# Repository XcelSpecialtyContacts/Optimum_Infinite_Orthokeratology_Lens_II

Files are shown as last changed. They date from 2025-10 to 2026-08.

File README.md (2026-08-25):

# Optimum Infinite Orthokeratology Lens II

## Overview

This project supports the production workflow for the **Optimum Infinite Orthokeratology Lens II** design at X-Cel Specialty Contacts.

The overall system is intended to:

1. Accept customer / ECP order inputs directly in **JD Edwards Configurator**
2. Generate the required production data in JDE, including the **Lab File** and **Invoice**
3. Generate DAC International ALM **point files** from JDE production data
4. Automatically invoke point-file generation during ALM job processing
5. Use a custom ALM manufacturing program (**LSID**) to cut lens surfaces from the generated point files
6. Support lathe-file generation through updates to **RGPLogin.exe**

This repository is primarily the source and documentation hub for the **`oiol2` point-file generator** and its integration into the broader manufacturing workflow.

---

## System Components

The complete production solution includes four major components:

1. **JD Edwards Configurator**
2. **`oiol2` Point File Generator**
3. **DAC ALM LSID (`lsXPF`)**
4. **RGPLogin.exe modifications**

Not all of these components are fully version-controlled in this repository. This repository focuses mainly on:

- the Python source code for `oiol2`
- launcher scripts used to invoke `oiol2`
- supporting configuration and data files
- tests
- documentation describing system integration

---

## Current Implementation Summary

### 1. JD Edwards Configurator

- A new item was created for this project: **Item 733**
- For Item 733, Customer Service enters the ECP's inputs directly into JDE Configurator
- No intermediate calculator / translator is required before entering order data into Configurator
- JDE produces a **Lab File** containing the data needed to generate lathe point files
- The invoice has been mocked up in the JDE **Test** environment
- Full testing of the invoice is still required before promotion to the **Live** environment

### 2. `oiol2` Point File Generator

`oiol2` is the Python program that reads production data and generates DAC ALM point files.

#### Original concept

The original plan was to host `oiol2` on a server and have the ALM call it remotely. In that design:

- the ALM would pass arguments identifying the lens/job to cut
- the server would generate the point files
- the server would return an exit code to the ALM
- the ALM would retrieve the generated point files and continue processing

This approach was not implemented due to credential, access, and IT support complexities between systems.

#### Implemented approach

The implemented solution runs `oiol2` **locally on the ALM PC**.

This avoids cross-system credential and server access issues. In the implemented design:

- the ALM PC runs a local 32-bit Python runtime
- `oiol2` is installed locally on the ALM PC
- the ALM invokes `oiol2` through a batch launcher
- `oiol2` generates the required point files locally
- the exit code is returned back to the ALM workflow

#### 32-bit runtime port

The development version of `oiol2` was originally built using:

- Python 3.11
- 64-bit Windows
- a Conda-based development environment

Because the ALM-connected PCs run **Windows 10 LTS 32-bit**, `oiol2` was ported to run under a standalone **Python 3.11 32-bit** installation.

Notes:

- `matplotlib` was removed from the ALM runtime path because plotting was only needed for development
- `numpy` required installation of the **Microsoft Visual C++ Redistributable**
- the 32-bit version was validated on the ALM-connected PC

#### Front-surface laser engraving

`oiol2` now includes the WO number as laser-writing data in the front-surface DAC point file.

The generated front point file uses the **`FRL`** format (front side, radial format, laser writing). The laser-writing block is written after the diagnostic-mark count and before the first surface definition.

For the current production configuration:

- the laser text is the WO number passed with `--wo`
- the engraving radius is calculated as `lens diameter / 2 - edge_offset_mm`
- the default engraving direction is **270.0 degrees**
- the default character height is **0.400 mm**
- the default character spacing factor is **1.0**
- the default edge offset is **0.400 mm**

The fixed laser-writing parameters are maintained in the `[laser_writing]` section of `lens_design.toml`, while the WO number and lens diameter are determined for each production job.

This implementation was tested successfully in the production ALM workflow.

### 3. DAC ALM LSID (`lsXPF`)

A new LSID named **`lsXPF`** was developed with John Vanover.

`lsXPF` is responsible for:

- processing the point files generated for the lens surface
- calling the `oiol2` launcher so point files can be generated when needed
- continuing the ALM cutting process after point files are available

### 4. RGPLogin.exe

The source for `RGPLogin.exe` is written in Microsoft VB.

This program was modified so that when a job is set up in production, it creates the appropriate **Lathe File** needed by the ALM workflow for this project.  Version 1.17 is required for this process.

---

## Process Flow

```mermaid
flowchart TD
    A[JDE Produces Lab File] --> B[RGPLogin Creates Lathe File]
    B --> C[ALM Reads Lathe File]
    C --> D[ALM Executes lsXPF]
    D --> E[lsXPF calls launcher script]
    E --> F[Launcher script executes oiol2.main]
    A --> G[oiol2 reads Lab File data]
    F --> G
    G --> H[oiol2 generates point files]
    H --> I[oiol2 returns exit code to launcher]
    I --> J[Launcher places point files in ALM-accessible location]
    J --> K[Launcher returns exit code to lsXPF]
    K --> L[lsXPF cuts surface using point file]
```

### Execution chain

**S1**
`D:\oiol2\call_oiol2_point_file_gen.bat --wo ###`

**E1**
`D:\Python32\python.exe -m oiol2.main --wo ###`

**S2**
`oiol2.main`

**L1**
`D:\oiol2\test_dacfiles\`

---

## Repository Purpose

This repository should contain the **source of truth** for the `oiol2` software and its deployment documentation.

It is intended to include:

* Python source code
* configuration templates
* supporting data files
* test code
* launcher scripts
* system documentation
* integration notes for JD Edwards, `lsXPF`, and `RGPLogin.exe`

It should **not** be used to store:

* machine-specific installed copies
* build artifacts
* virtual environments
* log files
* Python cache folders
* generated point files used only for testing or local runs

---

## Repository Layout

Planned / preferred layout:

```text
Optimum_Infinite_Orthokeratology_Lens_II/
│
├── README.md
├── .gitignore
├── pyproject.toml
├── pytest.ini
├── environment.yml
├── requirements.txt
├── requirements_win32.txt
├── requirements_32bit_runtime.txt
│
├── configs/
├── data/
├── docs/
├── scripts/
├── src/
│   └── oiol2/
├── tests/
├── examples/
└── archive/
```

### Key directories

* **`src/oiol2/`**
  Main Python package for point-file generation
* **`configs/`**
  Configuration templates and sample TOML files
* **`data/`**
  Lens design data and lookup/reference files
* **`scripts/`**
  Launcher and helper scripts used for ALM execution and testing
* **`tests/`**
  Automated tests for parser and geometry logic
* **`docs/`**
  Project documentation, architecture notes, deployment notes, and design references
* **`examples/`**
  Sample lab files, sample outputs, and example inputs/outputs as needed
* **`archive/`**
  Legacy or reference material retained for historical reasons but not part of the active runtime path

---

## Development vs Deployment

### Development environment

Development was originally performed using:

* Python 3.11
* 64-bit Windows
* Conda environment
* optional plotting for geometry/debug work

### Deployment environment

The ALM runtime environment uses:

* Windows 10 LTS 32-bit
* standalone Python 3.11 32-bit
* locally installed `oiol2`
* launcher batch script
* Microsoft Visual C++ Redistributable for `numpy`
* Reconfigured `XASPFRNT.TPL` file in the ALM folder on the DAC PC (see `docs/ALM_with_laser_set-up.md`)

---

## ALM Deployment Layout

Example deployment layout on the ALM PC:

```text
D:\
├── Python32\
└── OIOL2\
    ├── call_oiol2_point_file_gen.bat
    ├── configs\
    ├── data\
    ├── logs\
    ├── src\
    └── test_dacfiles\
```

This installed layout is documented for deployment purposes, but the installed copy itself should not be committed as a duplicate code tree in Git.

---

## Status

### Completed

- [X] Item 733 created in JD Edwards Configurator
- [X] Direct ECP input workflow established in Configurator
- [X] Lab File generation working in JDE
- [X] `oiol2` developed and working in development environment
- [X] `oiol2` ported to Python 3.11 32-bit runtime
- [X] local ALM execution model implemented
- [X] `lsXPF` LSID created to process point files and invoke `oiol2`
- [X] `RGPLogin.exe` modified to generate the required Lathe File
- [X] WO laser engraving integrated into the front-surface `FRL` point file
- [X] laser-writing implementation validated in production
- [X] complete invoice testing in JDE Test environment
- [X] move invoice changes to JDE Live environment after validation
- [X] Install `lsXPF` and `oiol2` on ALM03, ALM06, ALM07, and ALM08

### Open items

- [ ] create an `lsXPF` version for ALM01 and ALM02

---

## Runtime Notes

* Some Python modules (e.g., `numpy`, `sympy`) on the 32-bit ALM system require the **Microsoft Visual C++ Redistributable**
* plotting support was intentionally removed from the ALM runtime path
* machine-specific config files should not be committed to version control unless sanitized for reuse

---

## Notes

This repository documents a manufacturing integration effort that spans ERP configuration, production setup, ALM machine integration, and Python-based point-file generation. The Python code in this repository is only one part of the overall solution, but it is the primary software component maintained here.

---

## Maintainer

### [X-Cel Specialty Contacts](https://www.xcelspecialtycontacts.com/)

[Allen Gilliard](agilliar@xcelspecialtycontacts.com)

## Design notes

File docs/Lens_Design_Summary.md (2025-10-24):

## Constraints for Optimum Infinite Orthokeratology Lenses II
Patient Spherical Error:  -0.25 to -6.00 diopters
Patient Cylinder Error:  0.00 to -1.75 diopters
Lens Diameter:  9.5 to 12.0 mm
Center Thickness:
Central Base Curve Radius:  6.50 to 10.50 mm
Optical Zone Semi Chord: 2.50 to 3.50 mm
Return Zone Width: 0.75 to 1.5 mm
Return Zone Depth: 0 to 1.0 mm
Return Zone Radius: No constraint
Landing Zone Angle: 25$^\circ$ to 50$^\circ$
Landing Zone Width: 0.5 to 2.75 mm
Peripheral Edge Curve Width: minimum 0.04 mm
Dioptric Powers: -2.00 to +2.00 diopters
Lens Material: Optimum Infinite (tisilfocon A)

## X-Cel Specialty Contacts Othokeratology Lens Specifics
| Paramater | Maximum | Minimum | Increments |
|---|---|---|---|
| Lens Diamter (mm) | 12.0 | 9.5 | 0.1 |
| Central Zone Radius (diopter) | 51.875 | 32.125 | 0.125 |
| Central Zone Diameter (mm) | 7.0 | 5.0 | 0.1 |
| Return Zone Depth (mm) | 1.00 | 0.00 | 0.01 |
| Return Zone Width (mm) | 1.0 | 1.0 | 0 |
| Landing Zone Angle ($^\circ$) | 50 | 25 | 1 |
| Landing Zone Width (mm) | 2.75 | 0.50 | \* See Note |
| Peripheral Edge Curve Depth (mm) | 0.23 | 0.16 | 0.01 |
| Peripheral Edge Curve Width (mm) | 0.4 | 0.4 | 0 |
| Center Thickness Minimum (mm) | 0.09 | 0.50 | 0.01 |
| Central Zone Boundary Junction Thickness Minimum (mm) | 0.08 | 1.0 | \* See Note |
| Lens Power (diopter) | +2.00 | -2.00 | 0.25 |
| Edge Thickness (mm) | 0.11 | 0.11 | 0 |

### Notes:
1. ECP can specify Lens Diameter but the default is 10.5 mm.  The ECP can make adjustments to the diameter in 0.1 mm steps.
2. ECP can specify Central Zone Diameter but the default is 6.0 mm.  The ECP can make adjustments to the Central Zone diameter in 0.1 mm steps.
3. Central Zone Radius is initally selected by patient's flat K value and the patient's spherical error.  The ECP can make adjustments to the radius in 0.125 diopter steps.
4. Return Zone Depth is initally selected by patient's flat K value and the patient's spherical error.  The ECP can make adjustments to the depth in 0.01 mm steps.
5. Return Zone Width is set to 1.0 mm.
6. Landing Zone Angle is initally selected by patient's flat K value and the patient's spherical error.  The ECP can make adjustments to the angle in 1 degree steps.
7. Landing Zone Width is calculated.
8. ECP can specify Peripheral Edge Curve Depth but the default is 0.21 which generally equates to aproximately a 11.5 mm peripheral curve radius.  The ECP can make adjustments to the depth in 0.01 mm steps.
9. Peripheral Edge Curve Width is set to 0.4 mm.
10. ECP can specify Center Thickness but the default is 0.24 mm.  The ECP can make adjustments to the diameter in 0.01 mm steps.
11. Central Zone Boundary Junction Thickness Minimum is set to 0.18.
12. ECP can specify Lens Powerer but the default is +0.75 diopters.  The ECP can make adjustments to the diameter in 0.25 diopter steps.
13. Edge Thickness is set to 0.11 mm.

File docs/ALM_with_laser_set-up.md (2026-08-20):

To eliminate the ALM from looking for a BC to FC clocking alignment mark on axial symetric parts with laser engraving a file in the ALM control software will need to be edited.

Edit the file named XASPFRNT.TPL

Search for the function named `set_c_zero`.
Once found, a few lines into the function you will see `ERROR = 0`.
Insert a line after this line.

`if {torics+bisym+dmn}+otpts = 0 m99'

Save the file.

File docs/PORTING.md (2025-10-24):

| Legacy name | New name | Notes (units/sign) | Tests added | Date |
|---|---|---|---|---|
| SagSphere | sag_sphere | y in mm; raises if y>R | test_geometry_basic| 2025-10-21 |
| PowerFromRadius | radius_to_surface_power | air->lens, mm->D | test_geometry_basic| 2025-10-21 |

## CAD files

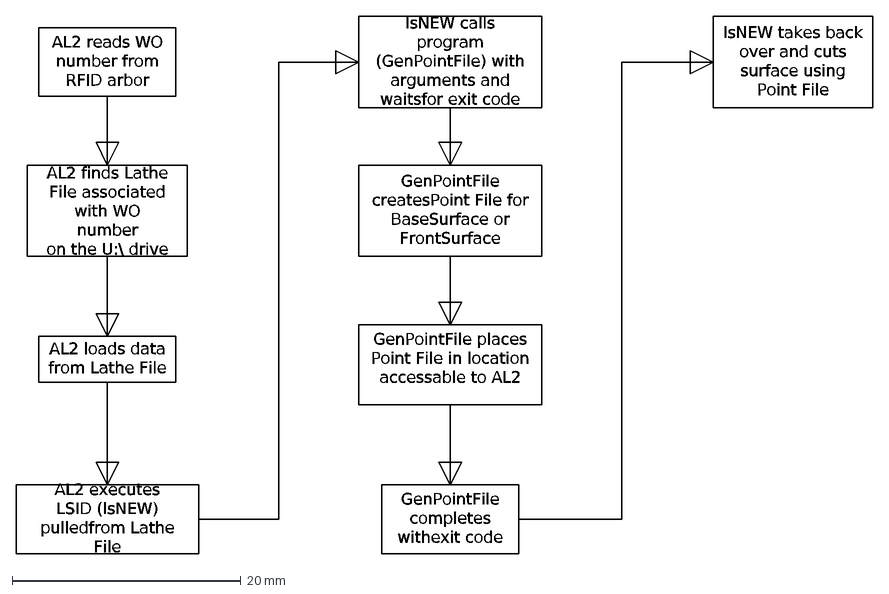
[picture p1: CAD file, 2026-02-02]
docs/ALM_Lathe_Process_2601290831.dxf
lsNEW calls program (GenPointFile) with arguments and waits for exit code
GenPointFile creates Point File for Base Surface or Front Surface
GenPointFile places Point File in location accessable to AL2
AL2 reads WO number from RFID arbor
AL2 finds Lathe File associated with WO number on the U:\ drive
AL2 loads data from Lathe File
AL2 executes LSID (lsNEW) pulled from Lathe File
GenPointFile completes with exit code
lsNEW takes back over and cuts surface using Point File

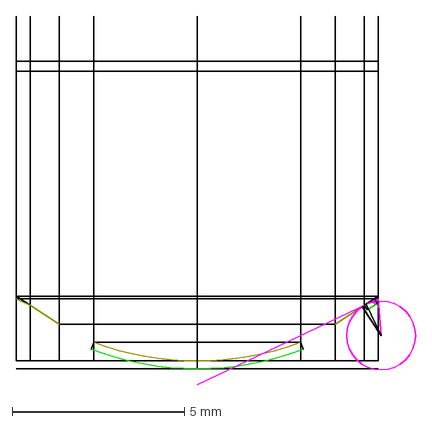
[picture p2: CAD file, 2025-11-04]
docs/design_mock_up_2510240940.dxf
11.6 x 10.7 mm

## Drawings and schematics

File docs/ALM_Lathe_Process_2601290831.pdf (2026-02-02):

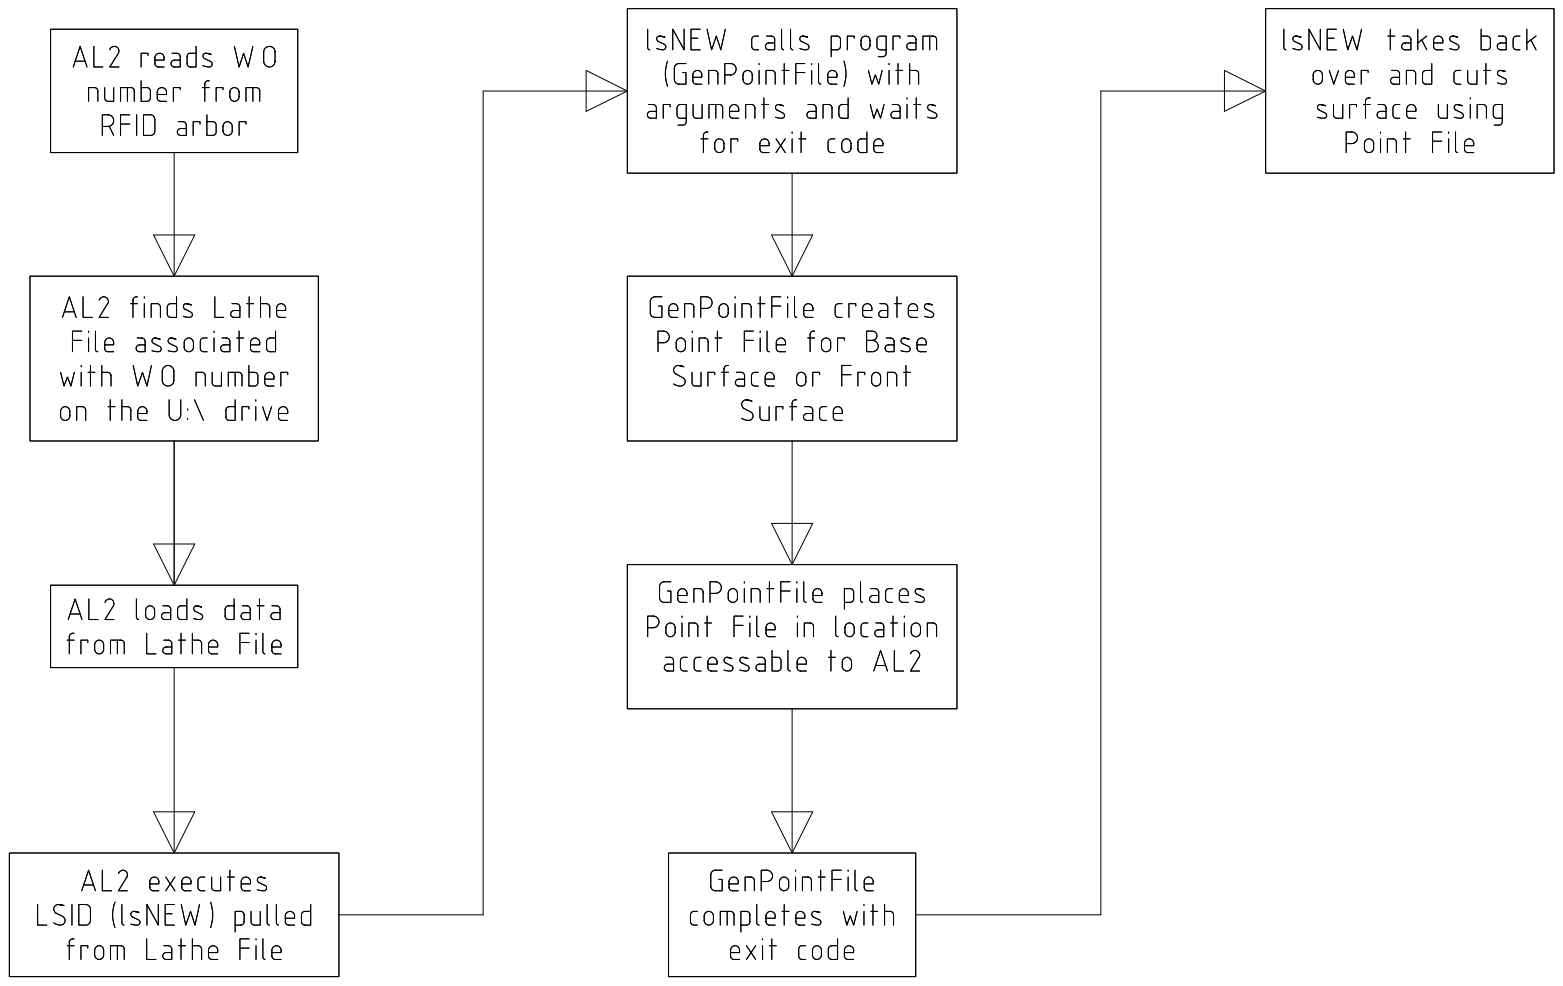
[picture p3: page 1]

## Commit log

2025-10-21 feat: scaffold OIOL2 with modular src package, config, scripts, tests, env
    [CRT_SKUs.csv]
2025-10-24 Working on the optic zone meridional points
    [design_mock_up_2510240940.dxf]
2025-10-31 Drafted code for calculating Base Surface
    [design_mock_up_2510240940.dxf]
2025-11-03 Drafted code for calculating Base Surface and Front Surface
    [design_mock_up_2510240940.dxf]
2025-11-04 Finished generating points.
    [#design_mock_up_2510240940.dxf, design_mock_up_2510240940.dxf]
2026-02-02 Last update
    [ALM_Lathe_Process_2601290831.dxf]
2026-03-04 Move ALM Lathe Process docs into docs/
    - Relocate DXF/PDF under docs/
    - Remove stray DXF backup file
    - Update .gitignore to prevent editor/backup artifacts
    [ALM_Lathe_Process_2601290831.dxf]
2026-03-16 Clean repository: remove caches, logs, generated files from version control
    [#design_mock_up_2510240940.dxf]
2026-03-16 Replace 64-bit baseline with 32-bit ALM implementation
    [ALM_Lathe_Process_2601290831.dxf, CRT_SKUs.csv, design_mock_up_2510240940.dxf]
2026-08-14 Add production laser engraving support
2026-08-20 Added instruction on how to modify the ALM with a laser so an automation error will not pop up.
2026-09-22 Added files for investigation of power targetting issue
